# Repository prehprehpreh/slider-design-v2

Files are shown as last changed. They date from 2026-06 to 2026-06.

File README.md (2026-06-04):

# Slider Design V2

Camera slider project with 3D printed parts, Arduino control, and Windows controller.

## Project Structure

- `3d_models/` - STL files for 3D printed slider components
- `firmware/` - Arduino sketch files for slider control
- `controller/` - Windows desktop controller application

## Components

### 3D Models
- `2040_slider_carriage_bottomV1.stl`
- `2040_slider_carriage_topV1.stl`
- `CameraUplateV1.stl`
- `Carriage_Base_V1.stl`
- `PanAxisCarriageV1.stl`

### Firmware
- Arduino Network Slider PTZ control
- CHATGPT Arduino Mega Code with NRF24

### Controller
- Windows Controller Python application

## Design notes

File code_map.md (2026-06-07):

# PTZ Slider — Code Map & System Analysis

> Generated after full analysis of the active Arduino Mega firmware and Python Windows controller.

---

## 1. System Architecture

```
PC Controller (Python/Kivy + Xbox gamepad)
    │ UDP send → Mega :44158
    │ UDP recv ← Mega :44159
    │ JSON persistence (~\Documents\Controller2\motor_params.json)
    ▼
Arduino Mega 2560
    ├── WIZ5100 Ethernet Shield
    ├── 128x64 I2C OLED (SSD1306 @ 0x3C)
    └── 4x stepper drivers (AccelStepper + MultiStepper)

Planned:
Arduino Nano + NRF24L01+PA+LNA ←→ Mega (needs NRF24 input path)
```

---

## 2. Hardware Pinout (Mega)

| Motor | Role | Step | Dir | MS1 | MS2 | TMC EN |
|---|---|---|-----|-----|-----|---|
| 1 | **Slide** | 3 | 2 | 10 | 11 | — |
| 2 | **Pan** | 31 | 30 | 32 | 33 | — |
| 3 | **Tilt** | 45 | 44 | 40 | 41 | — |
| 4 | **Zoom** | 48 | 49 | 37 | 35 | 50 |

- All MS pins set `HIGH` in `setup()` (likely 1/16 microstep).
- **Bug:** `ms1Pin2` is never set `HIGH` in `setup()`; line 81 writes `ms2Pin2` twice.

---

## 3. Input → Motor Mapping

| Source | Python Var | Arduino Var | Motor | Role |
|---|---|---|---|---|
| Left Stick X | `x_axis_left` | `x_axis_value_left` | Stepper1 | Slide |
| Left Stick Y | `y_axis_left` | — | — | **Unused** |
| Right Stick X | `x_axis_right` | `x_axis_value_right` | Stepper2 | Pan |
| Right Stick Y | `y_axis_right` | `y_axis_value` | Stepper3 | Tilt |
| Left Trigger | `trigger_left_mapped` | `trigger_left` | Stepper4 | Zoom (+) |
| Right Trigger | `trigger_right_mapped` | `trigger_right` | Stepper4 | Zoom (-) |

- Triggers are combined in Arduino: `target = (trigger_right + trigger_left) * 100`.
- Right trigger is stored negative in Python (`-(event.state / 255.0)`).

---

## 4. UDP Protocol

### PC → Mega (Commands)

| Command | Payload | Handler | Notes |
|---|---|---|---|
| `SET_JOYSTICK` | `xL,xR,yR,tL,tR` (5 floats) | `handleUDPRequests()` | Real-time analog control |
| `SEND_CURRENT_POS` | — | `sendCurrentMotorPositions()` | Triggers reply with positions |
| `SAVE_POS` | — | `saveMotorPositions()` | **Dead code** — no Python caller |
| `RECALL_POS` | — | `recallMotorPositions()` | **Dead code** — no Python caller |
| `SAVE_A` | — | `savePresetA()` | Save current pos to Preset A |
| `SAVE_B` | — | `savePresetB()` | Save current pos to Preset B |
| `RECALL_A` | — | `recallPresetA()` | Blocking syncMove to Preset A |
| `RECALL_B` | — | `recallPresetB()` | Blocking syncMove to Preset B |
| `UPDATE_LOOP` | `true` or `false` | Sets `loopPresets` | Enables/disables loop flag on Mega |
| `INCREASE_SPEED` | — | `msSpeed += 200` | Bumps slide max speed |
| `DECREASE_SPEED` | — | `msSpeed -= 200` | Drops slide max speed |

### Mega → PC (Replies)

| Message | Triggered By | Python Handler |
|---|---|---|
| `CURRENT_POS:m1,m2,m3,m4` | `SEND_CURRENT_POS` | `update_motor_positions()` |
| `PRESET_POS_A:m1,m2,m3,m4,PRESET_POS_B:m1,m2,m3,m4` | `SAVE_A` or `SAVE_B` | `update_preset_positions()` |
| `MSSPEED:val` | Speed change / `SET_MSSPEED` | Updates label + saves JSON |
| `PRESET_A_DONE` | End of `recallPresetA()` | If `loop_state`, sends `RECALL_B` |
| `PRESET_B_DONE` | End of `recallPresetB()` | If `loop_state`, sends `RECALL_A` |

### Setup Handshake (Mega Boot)

1. Mega waits for **any** UDP packet to learn controller IP/port.
2. Mega sends `GET_CURRENT_POS`.
3. Python loads `motor_params.json` and replies with:
   - `SET_POS m1,m2,m3,m4`
   - `SET_PRESET_A m1,m2,m3,m4`
   - `SET_PRESET_B m1,m2,m3,m4`
   - `SET_MSSPEED val`
4. Mega sets stepper current positions from saved values.
5. OLED shows `Data Loaded` or `Data Failed`.

---

## 5. Mega Firmware — Key Behaviors

### Main Loop (`loop()`)

```cpp
loop() {
    handleUDPRequests();          // Parse UDP, may BLOCK during preset recall
    if (5ms elapsed) {
        controlStepperMotors();  // Calculate target speeds, apply accel curves
    }
    stepper1.runSpeed();          // Execute steps
    stepper2.runSpeed();
    stepper3.runSpeed();
    stepper4.runSpeed();
}
```

### Motor Control (`controlStepperMotors()`)

- **Slide (Stepper1):** Custom asymmetric acceleration.
  - If speeding up: `current += min(10, diff * 0.002 + 0.02)`
  - If slowing down: `current -= min(10, -diff * 0.002 + 0.02)`
- **Pan (Stepper2), Tilt (Stepper3), Zoom (Stepper4):** Simple linear ramping.
  - `accel = 0.6` (pan/tilt), `0.75` (zoom)
  - `decel = 0.6` (pan/tilt), `0.75` (zoom)
- **Deadzone:** 10 (after scaling joystick *100), so ~10% deadzone.
- `max_speed_left` (slide) is dynamic, default 2000.
- Pan/tilt/zoom max speeds are hardcoded `const`: 100, 100, 75.

### syncMove (Blocking Preset Recall)

- Called by `recallPresetA()` and `recallPresetB()`.
- If already within `tolerance` (1000 steps) on **all 4 axes**, immediately sends `PRESET_X_DONE`.
- Otherwise:
  - Sets individual `moveTo()` targets.
  - Computes proportional max speed per motor: `speed = maxSpeed * (motorDistance / longestDistance)`.
  - **Blocking while-loop** calls `stepper.run()` until all motors arrive.
  - After arrival, resets all max speeds to `max_speed_left` and accel to 400.
  - Sends `PRESET_X_DONE`.
- **Critical:** During `syncMove`, `handleUDPRequests()` is NOT called. The Mega is unresponsive to new UDP packets and joystick updates.

### MultiStepper

- Added to all 4 steppers but only used by `recallMotorPositions()` (`SAVE_POS`/`RECALL_POS`).
- These commands have no callers in the Python app, so `MultiStepper` is effectively **unused**.

---

## 6. Python Controller — Key Behaviors

### Threads

| Thread | Purpose |
|---|---|
| Main | Kivy UI event loop |
| `joystick_input_thread` | Blocks on `inputs.get_gamepad()`, parses ABS/Key events, updates globals |
| `udp_receive_thread` | Blocks on `sock.recvfrom()`, parses Mega replies, orchestrates preset loop |

### Kivy Clock Intervals

| Function | Interval | Purpose |
|---|---|---|
| `send_joystick_data()` | 0.1s | Sends `SET_JOYSTICK` + `SEND_CURRENT_POS` |
| `virtualloop()` | 0.1s | If enabled, computes slider direction and sends `SET_JOYSTICK` |
| `save_params_periodically()` | 1.0s | Saves JSON if 5s elapsed since last save |

### Gamepad Mapping

| Input | Event Code | Action |
|---|---|---|
| Left Stick X | `ABS_X` | `x_axis_left` |
| Left Stick Y | `ABS_Y` | `y_axis_left` (**unused**) |
| Right Stick X | `ABS_RX` | `x_axis_right` |
| Right Stick Y | `ABS_RY` | `y_axis_right` |
| Left Trigger | `ABS_Z` | `trigger_left_mapped` |
| Right Trigger | `ABS_RZ` | `trigger_right_mapped` (negative) |
| D-Pad Left | `ABS_HAT0X = -1` | `RECALL_A` |
| D-Pad Right | `ABS_HAT0X = +1` | `RECALL_B` |
| D-Pad Up | `ABS_HAT0Y = -1` | Enable `virtualloop` |
| D-Pad Down | `ABS_HAT0Y = +1` | Disable `virtualloop` |
| A (South) | `BTN_SOUTH` | `UPDATE_LOOP false` + disable `loop_state` |
| Y (North) | `BTN_NORTH` | `UPDATE_LOOP true` + enable `loop_state` |
| X (West) | `BTN_WEST` | `SAVE_A` |
| B (East) | `BTN_EAST` | `SAVE_B` |
| RB | `BTN_TR` | `INCREASE_SPEED` |
| LB | `BTN_TL` | `DECREASE_SPEED` |

### Two Different Loop Modes

1. **`loop_state` (Preset Sync Loop):**
   - Enabled by `UPDATE_LOOP true` / disabled by `UPDATE_LOOP false`.
   - Python orchestrates A↔B by listening for `PRESET_A_DONE` / `PRESET_B_DONE` from Mega.
   - When `PRESET_A_DONE` arrives, Python waits 0.5s then sends `RECALL_B`.
   - When `PRESET_B_DONE` arrives, Python waits 0.5s then sends `RECALL_A`.
   - Mega handles the actual synchronized motion via `syncMove`.
   - **Result:** All 4 motors move proportionally between full preset positions.

2. **`virtualloop_enabled` (Software Position Loop):**
   - Python reads `current_pos1_label.text` to know slider position.
   - Computes `direction = +1` or `-1` to reach next target (`preset_a_slide` or `preset_b_slide`).
   - Sends `SET_JOYSTICK direction,xR,yR,tL,tR` every 0.1s.
   - Only drives Stepper1 (slide). Pan/tilt/zoom remain manually controlled.
   - Toggles target when within `tolerance` (600 steps).
   - **Result:** Slider ping-pongs between A and B using the normal joystick control path.

### JSON Persistence

**File:** `~/Documents/Controller2/motor_params.json`

```json
{
    "current_positions": { "motor1": 0, "motor2": 0, "motor3": 0, "motor4": 0 },
    "preset_a": { "motor1": 0, "motor2": 0, "motor3": 0, "motor4": 0 },
    "preset_b": { "motor1": 0, "motor2": 0, "motor3": 0, "motor4": 0 },
    "ms_speed": 800,
    "udp_ip": "192.168.5.60",
    "invert_left": false,
    "invert_right": false,
    "invert_ry": false,
    "sensitivity_right": 1.0
}
```

- Loaded at app startup; defaults used if missing.
- `current_positions` and presets updated from Mega replies.
- `sensitivity_right` scales `x_axis_right` and `y_axis_right` in Python.
- Saved automatically every 5 seconds.

---

## 7. Known Issues / Observations

- **`ms1Pin2` never set HIGH** in `setup()` (typo on line 81).
- **`findBiggestNumFloatArray`** takes unused `String option` parameter.
- **`y_axis_left` parsed but never sent** to Arduino (left stick Y is dead).
- **`SAVE_POS` / `RECALL_POS`** have Arduino handlers but no Python callers.
- **`multiStepper`** configured but unused for preset recalls.
- **Mega cannot distinguish multiple UDP clients.** `sendUDPMessage()` replies to `Udp.remoteIP()` / `Udp.remotePort()`. If PC and Nano both send, replies may go to the wrong device.
- **`virtualloop`** parses label text to get position rather than using a dedicated state variable.
- **Pan/tilt/zoom max speeds are hardcoded** `const` on Mega. Changing them requires firmware modification.

---

## 8. Implications for Nano+NRF24 Controller

To add the Nano remote, the Mega firmware will likely need the following changes:

### Dual-Path Input
The Mega must accept commands from both Ethernet (PC) and NRF24 (Nano). The archived code in `ORIGINAL FILES DO NOT EDIT/` had a dual-path structure that can be used as reference.

### Reply Routing
`sendUDPMessage()` currently replies to the last UDP sender. With two controllers, the Mega needs to either:
- Broadcast state updates to both paths, or
- Track which controller sent the request and reply accordingly, or
- Make the Nano a "fire-and-forget" sender that does not wait for replies.

### NRF24 Payload Limit (32 bytes)
The current ASCII protocol (`SET_JOYSTICK 0.123,0.456, ...`) exceeds 32 bytes easily. A **compact binary protocol** is strongly recommended for the Nano↔Mega radio link.

### Persistence Without PC
If the PC is offline, the Nano must provide initial positions/presets on Mega boot, or the Mega must store them internally (EEPROM / SD card).

### Nano Menu System
The Nano OLED will display:
- Slider speed (`msSpeed`)
- Joystick sensitivity
- Invert controls toggles
- A **Start button** to exit the menu and save changes.

These settings must either be applied on the Nano before transmission or communicated to the Mega.

### syncMove Blocking
During preset recall, the Mega is unresponsive for the duration of the move. The Nano should expect this, or the firmware should be refactored to make `syncMove` non-blocking (state-machine driven in `loop()`).

### Loop Orchestration
Currently `loop_state` (A↔B preset sync loop) is managed entirely by Python. If the Nano replaces the PC, it must either:
- Replicate the Python loop logic on the Nano, or
- Teach the Mega to loop autonomously (store a `loopActive` flag and self-trigger recalls).

### State Conflicts
If both PC and Nano are online simultaneously, they may send conflicting `SET_JOYSTICK` values or commands. The firmware currently processes every packet in arrival order with no priority or arbitration.

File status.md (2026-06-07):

# PTZ Slider Project Status

## Hardware

### Slider (On-Device) — Arduino Mega
- 4x stepper motors (Slide, Pan, Tilt, Zoom) via `AccelStepper` + `MultiStepper`
- WIZ5100 Ethernet shield for network control
- 128x64 OLED status display (SSD1306, I2C @ 0x3C)

### Network Controller — Windows PC
- Python/Kivy app with Xbox gamepad via `inputs` library
- UDP communication to/from Mega on ports 44158/44159
- JSON persistence at `~/Documents/Controller2/motor_params.json`

### Physical Wireless Controller — In Progress
- **Prototype board:** Arduino Uno (same pinout as final Nano, easier breadboarding)
- **Final board:** Arduino Nano (ATmega328P)
- **Radio:** NRF24L01+PA+LNA with breakout adapter (3.3V regulator on-board)
- **Display:** 0.96" SSD1306 OLED 128x64 I2C
- **Inputs:** 2x HW-504 analog joysticks, 7x tactile buttons, 1x mini SPDT toggle (power)
- **Button layout:** D-pad Left/Right (left side), A/B/X/Y (right side), Start (center)
- **Archived NRF24 Mega code:** `ORIGINAL FILES DO NOT EDIT/` — prior dual UDP+NRF24 firmware, kept as reference

---

## Current State

### Completed
- Network-based control system fully functional (Mega + Python/Kivy + Xbox gamepad)
- Real-time stepper control with acceleration curves and deadzone remapping
- Preset system: Save/Recall A and B positions across all 4 motors
- Preset looping (A ↔ B) orchestrated by Python controller via `PRESET_A/B_DONE` messages
- Virtual loop mode (software position tracking) in Python controller
- JSON persistence on PC for positions, presets, speed, inversion, sensitivity
- Initial setup handshake: Mega requests saved state from PC on boot
- Full code analysis documented in `code_map.md`
- Wiring diagram for Uno/Nano prototype documented in `wiring_diagram_uno_nano.md`

### Completed — NRF24 Physical Controller
- Dual-mode Mega firmware receives UDP or NRF24 (auto-switches based on Ethernet link)
- Compact binary packet protocol: 8-byte `ControllerPacket` with XOR checksum
- All 4 joystick axes, 6 buttons, OLED popup messages on actions
- **Loop control:** Nano broadcasts `loopEnabled` in bit 7 of every packet; Mega drains radio FIFO between `syncMove()` calls to get latest state
- **Dead battery handling:** If no packet for 5s, Mega defaults to continuing the loop
- Freeze bug fixed: `syncMove()` early-returns when already at target position

### Decided — Nano Controller Design
- **No virtual loop on Nano** — too complex, not needed on the physical remote
- **Nano sends:** joystick values + button states in compact binary every 50ms
- **NRF24 protocol:** 8-byte binary `ControllerPacket`, magic byte `0xAB`, bit 7 of `buttons` = loop state
- **Menu mode:** Start button toggles between normal control and OLED settings menu
  - In menu mode, no signals sent to Mega
  - Menu controls: speed, joystick sensitivity, invert axes
  - Settings saved to Nano EEPROM on Start press (exit)
  - Skeleton menu system to be built from the start, populated later
- **Prototyping on Uno** before finalizing on Nano — identical pinout

### Nano Pin Assignments (Uno + Nano)
| Function | Pin |
|---|-----|
| NRF24 CE | D8 |
| NRF24 CSN | D9 |
| NRF24 MOSI | D11 |
| NRF24 MISO | D12 |
| NRF24 SCK | D13 |
| OLED SDA | A4 |
| OLED SCL | A5 |
| Left Joystick X | A0 |
| Left Joystick Y | A1 |
| Right Joystick X | A2 |
| Right Joystick Y | A3 |
| Start Button | D2 |
| Button X (Save A) | D3 |
| Button Y (Loop ON) | D4 |
| D-pad Left (Recall A) | D5 |
| D-pad Right (Recall B) | D6 |
| Button A (Loop OFF) | D7 |
| Button B (Save B) | D10 |

---

## Open Decisions
1. **Where do presets live when PC is offline?**
   - Mega EEPROM? Nano EEPROM? Volatile only?
2. **Position feedback to Nano OLED?**
   - Requires Mega to broadcast `CURRENT_POS` back over NRF24

---

## Next Steps
1. Test loop stop/start repeatedly in a live run to confirm reliability
2. Add menu system to Nano (speed, sensitivity, invert axes) via Start button toggle
3. Save/load settings to Nano EEPROM
4. Update `README.md` to reflect current dual-mode firmware architecture
5. Consider Mega EEPROM persistence for presets when PC is offline

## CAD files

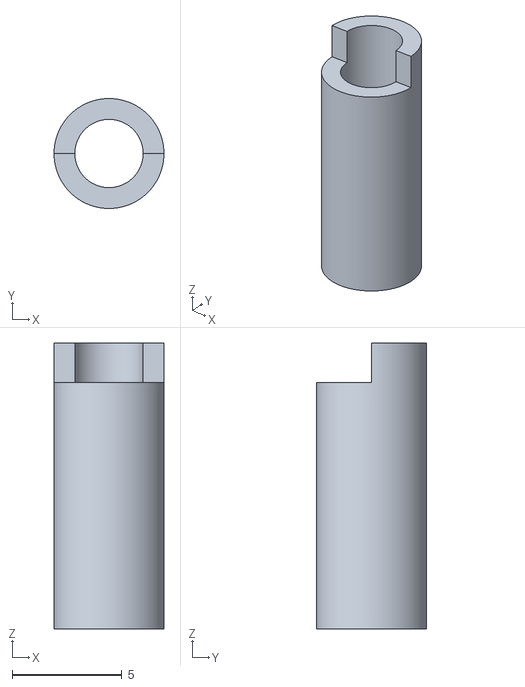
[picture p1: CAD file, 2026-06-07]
3d_models/3mm_to_5mm_wheel_bearing_spacer_centred.stl
5.00 x 5.00 x 13.0

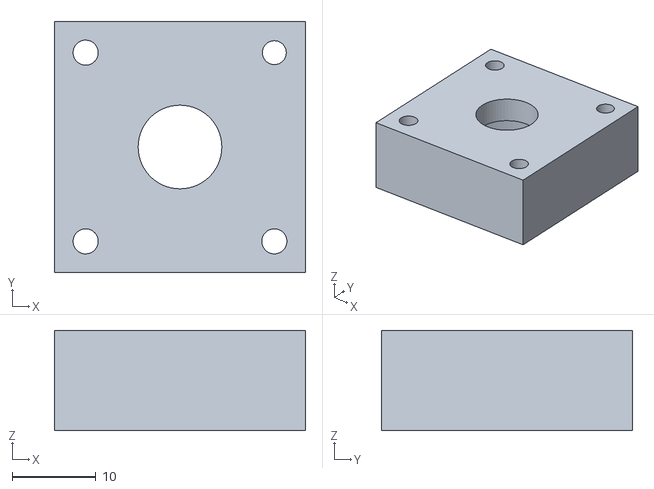
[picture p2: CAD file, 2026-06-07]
3d_models/PanBearingHolderV1.stl
30.0 x 30.0 x 12.0

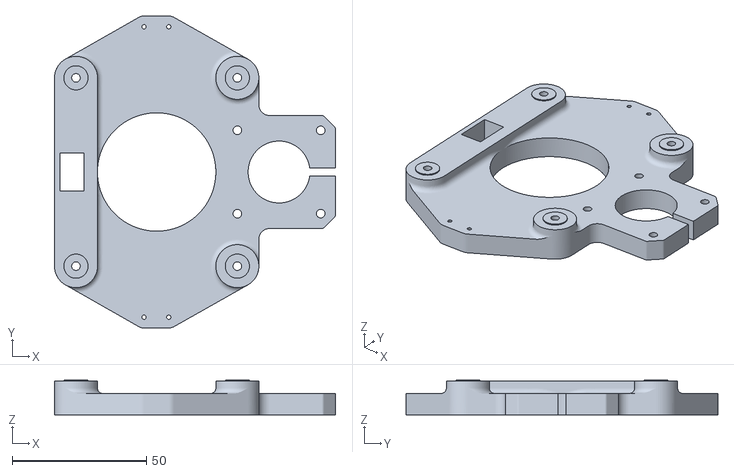
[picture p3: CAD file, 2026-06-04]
3d_models/2040_slider_carriage_bottomV1.stl
104.5 x 116.0 x 13.0

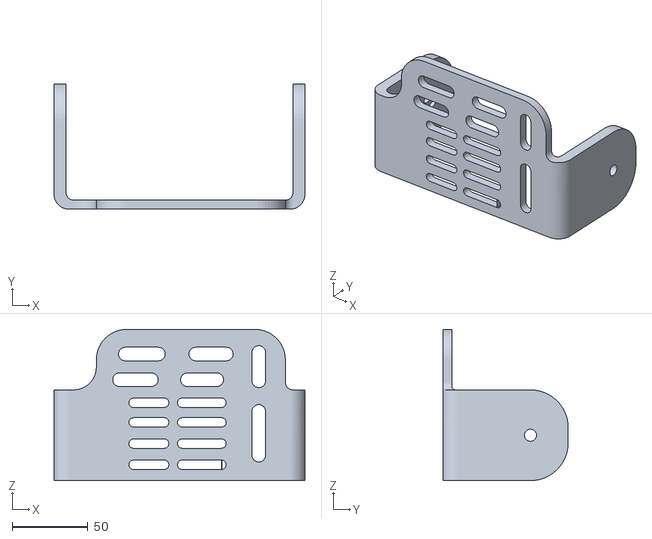
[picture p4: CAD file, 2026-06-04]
3d_models/CameraUplateV1.stl
166.0 x 83.0 x 100.0

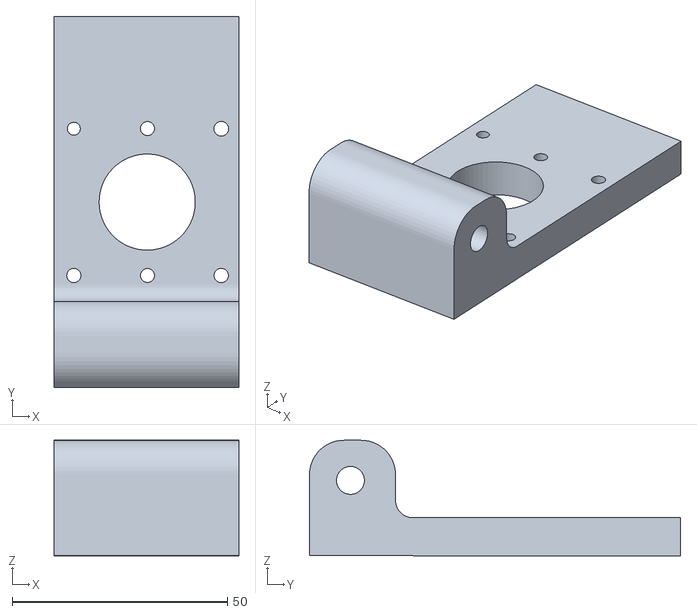
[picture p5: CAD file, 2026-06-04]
3d_models/Carriage_Base_V1.stl
43.0 x 86.2 x 26.8

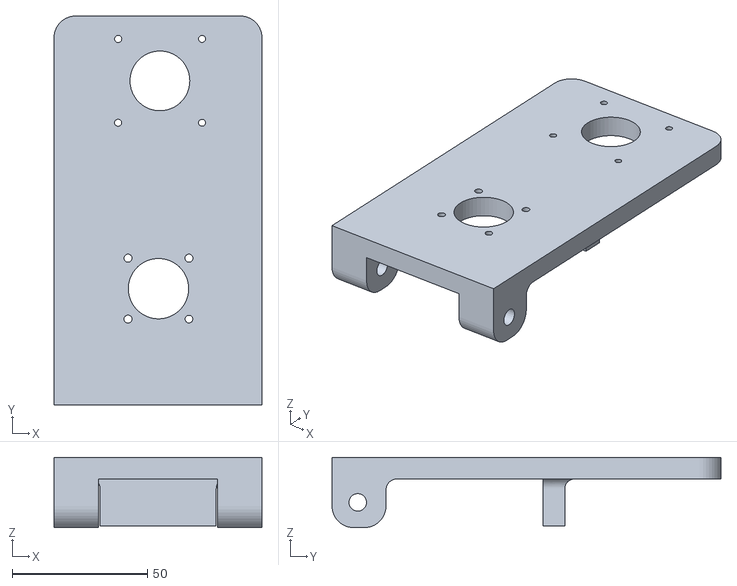
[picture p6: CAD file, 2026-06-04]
3d_models/PanAxisCarriageV1.stl
77.0 x 144.0 x 26.0

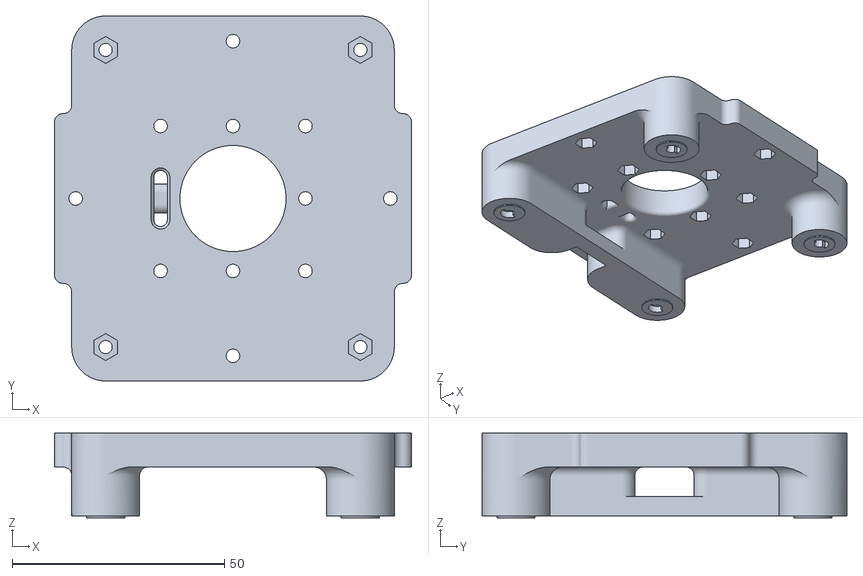
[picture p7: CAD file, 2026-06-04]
3d_models/2040_slider_carriage_topV1.stl
84.1 x 86.0 x 20.0

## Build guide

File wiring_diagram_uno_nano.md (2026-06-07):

# Uno/Nano Controller - Wiring Diagram

## Pin Reference

```
                    ┌─────────────────────────────────────────┐
                    │           ARDUINO UNO/NANO              │
                    │                                         │
    NRF24 CE ───────┤ D8                                      │
    NRF24 CSN ──────┤ D9                                      │
    Button B ───────┤ D10                                     │
                    │                                         │
    NRF24 MOSI ─────┤ D11 (ICSP)                              │
    NRF24 MISO ─────┤ D12 (ICSP)                              │
    NRF24 SCK ──────┤ D13 (ICSP)                              │
                    │                                         │
    OLED SDA ───────┤ A4 (I2C)                                │
    OLED SCL ───────┤ A5 (I2C)                                │
                    │                                         │
    L-Joystick Y ───┤ A1                                      │
    L-Joystick X ───┤ A0                                      │
    R-Joystick Y ───┤ A3                                      │
    R-Joystick X ───┤ A2                                      │
                    │                                         │
    Start Btn ──────┤ D2                                      │
    Button X ───────┤ D3                                      │
    Button Y ───────┤ D4                                      │
    D-pad Left ─────┤ D5                                      │
    D-pad Right ────┤ D6                                      │
    Button A ───────┤ D7                                      │
                    │                                         │
                    │   VIN ────┐                             │
                    │   GND ────┼──┐                          │
                    │   5V ─────┼──┼──┐                       │
                    │   3.3V ───┤  │  │                       │
                    └───────────┼──┼──┼───────────────────────┘
                                │  │  │
                                │  │  │
            ┌───────────────────┘  │  └───────────────┐
            │                      │                  │
            ▼                      ▼                  ▼
     ┌────────────┐        ┌────────────┐    ┌────────────┐
     │ TOGGLE     │        │  GND BUS   │    │  5V BUS    │
     │ SWITCH     │        │            │    │            │
     │ (Battery+) │        │ •────────  │    │ •────────  │
     └────────────┘        └────────────┘    └────────────┘
```

---

## Component Wiring Details

### 1. NRF24L01+ Breakout Adapter (Top-Left Area)

```
         ┌────────────────────────────────┐
         │   NRF24L01+ PA+LNA Breakout    │
         │                                │
         │  ┌──────────────────────────┐  │
         │  │  IRQ  │ CE │ CSN │ MOSI │  │
         │  │   NC  │ D8 │ D9  │  D11 │  │
         │  ├──────────────────────────┤  │
         │  │ MISO  │ SCK│ GND │  VCC │  │
         │  │  D12  │ D13│ GND │  5V  │  │
         │  └──────────────────────────┘  │
         │         8-Pin Header           │
         └────────────────────────────────┘
```

**Connections:**
- VCC → 5V (breakout has 3.3V regulator)
- GND → GND
- MOSI → D11
- MISO → D12  
- SCK → D13
- CE → D8
- CSN → D9
- IRQ → Not connected

---

### 2. OLED SSD1306 128x64 I2C (Top Area)

```
        ┌─────────────────────┐
        │    OLED DISPLAY   │
        │   ┌───────────┐   │
        │   │           │   │
        │   │  128x64   │   │
        │   │   I2C     │   │
        │   │           │   │
        │   └───────────┘   │
        │                   │
        │  VCC GND SCL SDA  │
        │   │   │   │   │   │
        └───┼───┼───┼───┼───┘
            │   │   │   │
            5V  GND A5  A4
```

**Connections:**
- VCC → 5V
- GND → GND
- SCL → A5
- SDA → A4

---

### 3. Left Joystick - HW-504 (Slide Control)

```
           ┌───────────────────┐
           │   HW-504 Module   │
           │                   │
           │        ↑          │
           │     Y-axis        │
           │    (unused)       │
           │        ↓          │
           │                   │
           │ ←  X-axis  →      │
           │   (Slide L/R)     │
           │                   │
           │  ┌─────────────┐  │
           │  │   Push-btn  │  │
           │  │   (unused)  │  │
           │  └─────────────┘  │
           └───────────────────┘
           
           Pinout (from left to right):
           ┌───┬───┬───┬───┬───┐
           │GND│+5V│VRX│VRY│ SW│
           └───┴───┴───┴───┴───┘
            │   │   │   │   │
            │   │   │   │   └── NC (or D2 for joystick button)
            │   │   │   └────── A1 (Y-axis, currently unused)
            │   │   └────────── A0 (X-axis, Slide control)
            │   └────────────── 5V
            └────────────────── GND
```

---

### 4. Right Joystick - HW-504 (Pan/Tilt Control)

```
           ┌───────────────────┐
           │   HW-504 Module   │
           │                   │
           │        ↑          │
           │    Y-axis         │
           │   (Tilt U/D)      │
           │        ↓          │
           │                   │
           │ ←  X-axis  →      │
           │  (Pan L/R)        │
           │                   │
           │  ┌─────────────┐  │
           │  │   Push-btn  │  │
           │  │   (unused)  │  │
           │  └─────────────┘  │
           └───────────────────┘
           
           Pinout:
           ┌───┬───┬───┬───┬───┐
           │GND│+5V│VRX│VRY│ SW│
           └───┴───┴───┴───┴───┘
            │   │   │   │   │
            │   │   │   │   └── NC (or D10 for joystick button)
            │   │   │   └────── A3 (Y-axis, Tilt)
            │   │   └────────── A2 (X-axis, Pan)
            │   └────────────── 5V
            └────────────────── GND
```

---

### 5. Button Layout - Controller Face

```
         ╔═══════════════════════════════════════╗
         ║                                       ║
         ║           ┌─────────┐      OLED       ║
         ║           │ START   │    ┌─────┐      ║
         ║           │   D2    │    │     │      ║
         ║           └─────────┘    │ SSD │      ║
         ║                          │1306 │      ║
         ║   ┌─────┐                │12864│      ║
         ║   │  ←  │                └─────┘      ║
         ║   │ D5  │                           ║
         ║   ├─────┤                             ║
         ║   │  →  │                             ║
         ║   │ D6  │                             ║
         ║   └─────┘                             ║
         ║                                       ║
         ║   D-PAD (Left)        BUTTONS (Right) ║
         ║   (2-way)                               ║
         ║                              ┌───┐    ║
         ║                         ┌────┤ Y │    ║
         ║                         │ D4 └───┘    ║
         ║                    ┌────┴────┐        ║
         ║                   ┌┤   X     ├┐       ║
         ║                   ├┤  D3     ├┤       ║
         ║                   └┤    ┌────┼┘       ║
         ║                    └───┬┘ B  │        ║
         ║                        │ D10 │        ║
         ║                   ┌────┴────┘        ║
         ║                   │    A             ║
         ║                   │   D7             ║
         ║                   └────────          ║
         ║                                       ║
         ╚═══════════════════════════════════════╝
```

**Button Wiring (ALL buttons):**
- One side of button → Arduino Pin
- Other side of button → GND
- Code uses `INPUT_PULLUP`, so LOW = pressed

**Button Functions in Normal Mode:**
- **D-pad Left (D5):** Recall Preset A
- **D-pad Right (D6):** Recall Preset B
- **A (D7):** Save Preset A
- **B (D10):** Save Preset B
- **X (D3):** Loop ON
- **Y (D4):** Loop OFF
- **Start (D2):** Enter/Exit Menu

---

### 6. Power Switch

```
    Battery (+) ──┬──► (Toggle Switch Center Pin)
                  │
                  │   ┌───────────────┐
                  └──►│  Toggle Switch │
                      │   (SPDT)       │
                      │   ┌──┬──┬──┐   │
                      └───┤NC│ C │NO├───┘
                          └──┴──┴──┘
                               │
                               ▼
                         To Arduino
                            VIN
                               
    Battery (-) ─────────► To Arduino
                              GND
```

**Simple Inline Wiring:**
- Cut positive battery wire
- Connect one end to switch center pin
- Connect other end to one outer pin
- When switch is flipped that direction, circuit completes

---

## Breadboard Layout - Visual Guide

```
    ┌─────────────────────────────────────────────────────────────────────────┐
    │                          BREADBOARD TOP VIEW                            │
    │                                                                         │
    │  ┌─────────────────────────────────────────────────────────────────┐   │
    │  │                         POWER RAILS                              │   │
    │  │  ┌───────────────┐    ┌───────────────┐    ┌───────────────┐  │   │
    │  │  │ RED (5V)      │    │ BLU (3.3V)    │    │ BLK (GND)     │  │   │
    │  │  │ █████████████ │    │ (unused)      │    │ █████████████ │  │   │
    │  │  └───────────────┘    └───────────────┘    └───────────────┘  │   │
    │  └─────────────────────────────────────────────────────────────────┘   │
    │                                                                         │
    │  ┌─────────────────────────────────────────────────────────────────┐   │
    │  │  AREA 1: NRF24 (Top Left)                                        │   │
    │  │                                                                  │   │
    │  │        ┌────────────────────────┐                               │   │
    │  │        │   NRF24 Breakout       │                               │   │
    │  │        │                        │                               │   │
    │  │        │  VCC ─────► RED rail  │                               │   │
    │  │        │  GND ─────► BLK rail   │                               │   │
    │  │        │  D11 ─────► Blue wire  │                               │   │
    │  │        │  D12 ─────► Yel wire   │                               │   │
    │  │        │  D13 ─────► Wht wire   │                               │   │
    │  │        │  D8  ─────► Org wire   │                               │   │
    │  │        │  D9  ─────► Ppl wire   │                               │   │
    │  │        └────────────────────────┘                               │   │
    │  └─────────────────────────────────────────────────────────────────┘   │
    │                                                                         │
    │  ┌─────────────────────────────────────────────────────────────────┐   │
    │  │  AREA 2: OLED (Top Center)                                       │   │
    │  │                                                                  │   │
    │  │        ┌────────────────────────┐                               │   │
    │  │        │    OLED 128x64       │                               │   │
    │  │        │                      │                               │   │
    │  │        │  VCC ─────► RED rail │                               │   │
    │  │        │  GND ─────► BLK rail  │                               │   │
    │  │        │  SCL ─────► A5        │                               │   │
    │  │        │  SDA ─────► A4        │                               │   │
    │  │        └────────────────────────┘                               │   │
    │  └─────────────────────────────────────────────────────────────────┘   │
    │                                                                         │
    │  ┌─────────────────────────────────────────────────────────────────┐   │
    │  │  AREA 3: JOYSTICKS (Middle)                                      │   │
    │  │                                                                  │   │
    │  │   Left Joystick              Right Joystick                     │   │
    │  │   ┌────────────┐             ┌────────────┐                   │   │
    │  │   │   ──────   │             │   ──────   │                   │   │
    │  │   │  │    │   │             │  │    │   │                   │   │
    │  │   │   ──────   │             │   ──────   │                   │   │
    │  │   └────────────┘             └────────────┘                   │   │
    │  │      │  │  │  │                │  │  │  │                     │   │
    │  │      │  │  │  │                │  │  │  │                     │   │
    │  │     GND 5V A0 A1              GND 5V A2 A3                    │   │
    │  │      │  │  │  │                │  │  │  │                     │   │
    │  │      │  │  │  │                │  │  │  │                     │   │
    │  │      └──┴──┴──┘                └──┴──┴──┘                     │   │
    │  │         │                        │                            │   │
    │  │         └───────► Both share RED and BLK rails                │   │
    │  └─────────────────────────────────────────────────────────────────┘   │
    │                                                                         │
    │  ┌─────────────────────────────────────────────────────────────────┐   │
    │  │  AREA 4: BUTTONS (Bottom) - Left Side = D-Pad (2-way)           │   │
    │  │                                                                  │   │
    │  │                                                                  │   │
    │  │           ┌───┐    ┌───┐                                         │   │
    │  │           │ ← │    │ → │                                         │   │
    │  │       D5  └───┘    └───┘  D6                                   │   │
    │  │      (Recall A)   (Recall B)                                     │   │
    │  │                                                                  │   │
    │  │  Center: ┌─────────┐  (Start/Menu)                             │   │
    │  │          │   ●     │  D2                                        │   │
    │  │          └─────────┘                                             │   │
    │  │                                                                  │   │
    │  │  Right Side: ┌───┐ ┌───┐                                       │   │
    │  │              │ Y │ │ X │  D4, D3                               │   │
    │  │              └───┘ └───┘                                       │   │
    │  │              ┌───┐ ┌───┐                                       │   │
    │  │              │ B │ │ A │  D10, D7                              │   │
    │  │              └───┘ └───┘                                       │   │
    │  │                                                                  │   │
    │  │  ALL buttons: One pin to Arduino, other pin to GND             │   │
    │  └─────────────────────────────────────────────────────────────────┘   │
    │                                                                         │
    │  ┌─────────────────────────────────────────────────────────────────┐   │
    │  │  AREA 5: ARDUINO (Right Edge)                                    │   │
    │  │                                                                  │   │
    │  │   ┌──────────────────────────────────────┐                      │   │
    │  │   │          ARDUINO UNO/NANO            │                      │   │
    │  │   │                                      │                      │   │
    │  │   │  D0  D1  D2  D3  D4  D5  D6  D7  D8  │                      │   │
    │  │   │  NC  NC  ○   ○   ○   ○   ○   ○   ○   │  ○ = used            │   │
    │  │   │                                      │                      │   │
    │  │   │  D9  D10 D11 D12 D13 GND AREF SDA  │                      │   │
    │  │   │  ○   ○   ○   ○   ○   BLK NC  A4    │                      │   │
    │  │   │                                      │                      │   │
    │  │   │  SCL ─► A5                           │                      │   │
    │  │   │  ICSP header (for NRF24 SPI)          │                      │   │
    │  │   │                                      │                      │   │
    │  │   │  PWR: VIN GND 5V  3.3V              │                      │   │
    │  │   │       │   │   │   NC                │                      │   │
    │  │   │       │   │   │                     │                      │   │
    │  │   │       └───┴───┘                     │                      │   │
    │  │   │           │                        │                      │   │
    │  │   │           └──► To Power Switch     │                      │   │
    │  │   └──────────────────────────────────────┘                      │   │
    │  └─────────────────────────────────────────────────────────────────┘   │
    │                                                                         │
    └─────────────────────────────────────────────────────────────────────────┘
```

---

## Wire Color Code Suggestion

| Color | Use | Examples |
|---|-----|---|
| **Red** | 5V Power | VCC, +5V pins |
| **Black** | Ground | GND pins |
| **White** | Analog signals | Joystick X/Y |
| **Blue** | Digital/SPI | D11, D12, D13 |
| **Green** | Control signals | CE, CSN, Buttons |
| **Yellow** | I2C | SDA, SCL |
| **Orange** | Special functions | D8, D9 |
| **Purple** | Unused/Extra | — |

---

## Quick Reference - All Connections

| Component | Pin/Function | Arduino Pin | Notes |
|---|---|---|---|
| **NRF24** | VCC | 5V | Has regulator |
| | GND | GND | |
| | CE | D8 | |
| | CSN | D9 | |
| | MOSI | D11 | SPI |
| | MISO | D12 | SPI |
| | SCK | D13 | SPI |
| **OLED** | VCC | 5V or 3.3V | Check module |
| | GND | GND | |
| | SCL | A5 | I2C |
| | SDA | A4 | I2C |
| **L-Joystick** | +5V | 5V | |
| | GND | GND | |
| | VRX (X) | A0 | Slide |
| | VRY (Y) | A1 | Unused currently |
| **R-Joystick** | +5V | 5V | |
| | GND | GND | |
| | VRX (X) | A2 | Pan |
| | VRY (Y) | A3 | Tilt |
| **Buttons** | All one side | Pins D2, D3, D4, D5, D6, D7, D10 | Pullup enabled |
| | All other side | GND | Common ground |
| **Power** | Switch → VIN | VIN | 7-12V input |
| | Battery - | GND | Common ground |

---

## Uno vs Nano Differences

| Feature | Uno | Nano |
|---|-----|---|
| **Button X (D3)** | ✅ Available | ✅ Available |
| **Button Y (D4)** | ✅ Available | ✅ Available |
| **Breadboard** | Headers pre-installed | Solder or use adapter |
| **USB** | Standard B | Mini-B or Micro |
| **Size** | Larger | Smaller |

All 7 buttons work identically on both Uno and Nano using digital pins D2-D7 and D10.

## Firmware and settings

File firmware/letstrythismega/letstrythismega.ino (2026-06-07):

#include <AccelStepper.h>
#include <Ethernet.h>
#include <EthernetUDP.h>
#include <MultiStepper.h>
#include <SPI.h>
#include <Wire.h>
#include <Adafruit_SSD1306.h>
#include <RF24.h>

// Ethernet settings
byte mac[] = { 0xA8, 0x61, 0x0A, 0xAE, 0x03, 0x30 };
unsigned int localPort = 44158;
const bool USE_STATIC_IP = true;
IPAddress staticIP(192, 168, 1, 177);
EthernetUDP Udp;
char packetBuffer[255];

// NRF24 settings
#define NRF_CE  8
#define NRF_CSN 9
RF24 radio(NRF_CE, NRF_CSN);
const byte rfAddress[6] = "00001";

// Compact binary packet (must match Nano)
struct __attribute__((packed)) ControllerPacket {
    uint8_t magic;
    int8_t  lx;
    int8_t  ly;
    int8_t  rx;
    int8_t  ry;
    uint8_t buttons;
    uint8_t checksum;
};
ControllerPacket rxPacket;

// Define OLED settings
#define SCREEN_WIDTH 128
#define SCREEN_HEIGHT 64
#define OLED_RESET -1
Adafruit_SSD1306 display(SCREEN_WIDTH, SCREEN_HEIGHT, &Wire, OLED_RESET);
bool oledOK = false;

// Stepper motor pins
const int stepPin1 = 3, dirPin1 = 2, ms1Pin1 = 10, ms2Pin1 = 11;
const int stepPin2 = 31, dirPin2 = 30, ms1Pin2 = 32, ms2Pin2 = 33;
const int stepPin3 = 45, dirPin3 = 44, ms1Pin3 = 40, ms2Pin3 = 41;
const int stepPin4 = 48, dirPin4 = 49, ms1Pin4 = 37, ms2Pin4 = 35, tmcEnPin4 = 50;

AccelStepper stepper1(AccelStepper::DRIVER, stepPin1, dirPin1);
AccelStepper stepper2(AccelStepper::DRIVER, stepPin2, dirPin2);
AccelStepper stepper3(AccelStepper::DRIVER, stepPin3, dirPin3);
AccelStepper stepper4(AccelStepper::DRIVER, stepPin4, dirPin4);
MultiStepper multiStepper;

// Joystick input variables (buffered)
float x_axis_value_left = 0.0, x_axis_value_right = 0.0, y_axis_value = 0.0, trigger_left = 0.0, trigger_right = 0.0;
float msSpeed = 2000, slideSpeed = 20;
long saved_position1 = 0, saved_position2 = 0, saved_position3 = 0, saved_position4 = 0;
bool loopPresets = false;
bool autoLoopRunning = false;
long presetAPositions[] = {0, 0, 0, 0}, presetBPositions[] = {0, 0, 0, 0};

// Motor control variables
int max_speed_left = msSpeed;
const int max_speed_right = 100;
const int max_speed_y = 100;
const int max_speed_zoom = 75;

const float acceleration_rate_left = 10;
const float deceleration_rate_left = 10;
const float acceleration_rate_right = 0.6;
const float deceleration_rate_right = 0.6;
const float acceleration_rate_y = 0.6;
const float deceleration_rate_y = 0.6;
const float acceleration_rate_zoom = 0.75;
const float deceleration_rate_zoom = 0.75;

const int deadzone = 10;

float current_speed_left = 0;
float current_speed_right = 0;
float current_speed_y = 0;
float current_speed_zoom = 0;

// Timeout for waiting for controller response (ms) for positions/presets
const unsigned long CONTROLLER_TIMEOUT = 15000;
const unsigned long updateInterval = 5;
unsigned long previousMillis = 0;
const unsigned long displayInterval = 200;
unsigned long previousDisplayMillis = 0;

// Setup state flags
bool setupComplete = false;
bool posReceived = false;
bool presetAReceived = false;
bool presetBReceived = false;
bool ethernetActive = false;
uint8_t lastRemoteButtonMask = 0;

void setup() {
    Serial.begin(115200);
    while (!Serial) { ; }
    Serial.println(F("=== Mega PTZ Slider Boot ==="));
    Serial.println(F("1. Pins init..."));

    // Initialize hardware pins
    pinMode(ms1Pin1, OUTPUT); pinMode(ms2Pin1, OUTPUT);
    pinMode(ms1Pin2, OUTPUT); pinMode(ms2Pin2, OUTPUT);
    pinMode(ms1Pin3, OUTPUT); pinMode(ms2Pin3, OUTPUT);
    pinMode(ms1Pin4, OUTPUT); pinMode(ms2Pin4, OUTPUT);
    pinMode(tmcEnPin4, OUTPUT);
    digitalWrite(ms1Pin1, HIGH); digitalWrite(ms2Pin1, HIGH);
    digitalWrite(ms2Pin2, HIGH); digitalWrite(ms2Pin2, HIGH);
    digitalWrite(ms1Pin3, HIGH); digitalWrite(ms2Pin3, HIGH);
    digitalWrite(ms1Pin4, HIGH); digitalWrite(ms2Pin4, HIGH);
    digitalWrite(tmcEnPin4, LOW);

    Serial.println(F("2. Steppers init..."));
    // Initialize stepper settings
    stepper1.setMaxSpeed(max_speed_left);
    stepper2.setMaxSpeed(max_speed_left);
    stepper3.setMaxSpeed(max_speed_left);
    stepper4.setMaxSpeed(max_speed_left);
    multiStepper.addStepper(stepper1);
    multiStepper.addStepper(stepper2);
    multiStepper.addStepper(stepper3);
    multiStepper.addStepper(stepper4);

    Serial.println(F("3. Ethernet begin..."));
    if (USE_STATIC_IP) {
        Ethernet.begin(mac, staticIP);
        Serial.print(F("Static IP: ")); Serial.println(Ethernet.localIP());
    } else {
        Ethernet.begin(mac);
    }
    Serial.println(F("4. UDP begin..."));
    Udp.begin(localPort);
    Serial.println(F("5. Waiting 1s for link..."));
    delay(1000);

    Serial.println(F("6. Checking link status..."));
    EthernetLinkStatus link = Ethernet.linkStatus();
    ethernetActive = (link == LinkON);
    Serial.print(F("Ethernet link status: "));
    if (link == LinkON) Serial.println(F("ON"));
    else if (link == LinkOFF) Serial.println(F("OFF"));
    else Serial.println(F("UNKNOWN"));
    Serial.print(F("ethernetActive = ")); Serial.println(ethernetActive ? F("true") : F("false"));

    Serial.println(F("7. OLED init..."));
    Wire.begin();
    delay(100);
    oledOK = display.begin(SSD1306_SWITCHCAPVCC, 0x3C);
    if (oledOK) {
        Serial.println(F("OLED: OK"));
        display.clearDisplay();
        display.setTextSize(1);
        display.setTextColor(SSD1306_WHITE);
    } else {
        Serial.println(F("OLED: NOT FOUND"));
    }

    Serial.println(F("8. Mode selection..."));
    if (ethernetActive) {
        Serial.println(F("Mode: ETH (UDP)"));
        if (oledOK) {
            display.setCursor(0, 0);
            display.println("ETH Mode");
            display.println(Ethernet.localIP());
            display.display();
        }

        bool controllerFound = false;
        unsigned long waitStart = millis();
        while (!controllerFound && (millis() - waitStart < 10000)) {
            int packetSize = Udp.parsePacket();
            if (packetSize) {
                int len = Udp.read(packetBuffer, 255);
                if (len > 0) packetBuffer[len] = 0;
                controllerFound = true;
            }
            delay(10);
        }

        if (controllerFound) {
            int retryCount = 0;
            const int maxRetries = 3;
            while (retryCount < maxRetries && (!posReceived || !presetAReceived || !presetBReceived)) {
                sendUDPMessage("GET_CURRENT_POS");
                if (oledOK) {
                    display.clearDisplay();
                    display.setCursor(0, 0);
                    display.println("Requesting Data...");
                    display.setCursor(0, 10);
                    display.println(Ethernet.localIP());
                    display.display();
                }

                posReceived = false;
                presetAReceived = false;
                presetBReceived = false;
                unsigned long startTime = millis();

                while (millis() - startTime < CONTROLLER_TIMEOUT) {
                    int packetSize = Udp.parsePacket();
                    if (packetSize) {
                        int len = Udp.read(packetBuffer, 255);
                        if (len > 0) packetBuffer[len] = 0;
                        String response = String(packetBuffer);
                        if (response.startsWith("SET_POS")) {
                            int comma1 = response.indexOf(',');
                            int comma2 = response.indexOf(',', comma1 + 1);
                            int comma3 = response.indexOf(',', comma2 + 1);
                            saved_position1 = atol(response.substring(7, comma1).c_str());
                            saved_position2 = atol(response.substring(comma1 + 1, comma2).c_str());
                            saved_position3 = atol(response.substring(comma2 + 1, comma3).c_str());
                            saved_position4 = atol(response.substring(comma3 + 1).c_str());
                            stepper1.setCurrentPosition(saved_position1);
                            stepper2.setCurrentPosition(saved_position2);
                            stepper3.setCurrentPosition(saved_position3);
                            stepper4.setCurrentPosition(saved_position4);
                            posReceived = true;
                        } else if (response.startsWith("SET_PRESET_A")) {
                            int comma1 = response.indexOf(',');
                            int comma2 = response.indexOf(',', comma1 + 1);
                            int comma3 = response.indexOf(',', comma2 + 1);
                            presetAPositions[0] = atol(response.substring(12, comma1).c_str());
                            presetAPositions[1] = atol(response.substring(comma1 + 1, comma2).c_str());
                            presetAPositions[2] = atol(response.substring(comma2 + 1, comma3).c_str());
                            presetAPositions[3] = atol(response.substring(comma3 + 1).c_str());
                            presetAReceived = true;
                        } else if (response.startsWith("SET_PRESET_B")) {
                            int comma1 = response.indexOf(',');
                            int comma2 = response.indexOf(',', comma1 + 1);
                            int comma3 = response.indexOf(',', comma2 + 1);
                            presetBPositions[0] = atol(response.substring(12, comma1).c_str());
                            presetBPositions[1] = atol(response.substring(comma1 + 1, comma2).c_str());
                            presetBPositions[2] = atol(response.substring(comma2 + 1, comma3).c_str());
                            presetBPositions[3] = atol(response.substring(comma3 + 1).c_str());
                            presetBReceived = true;
                        } else if (response.startsWith("SET_MSSPEED")) {
                            msSpeed = response.substring(11).toFloat();
                            max_speed_left = msSpeed;
                        }
                    }
                    delay(10);
                    if (posReceived && presetAReceived && presetBReceived) break;
                }

                if (!posReceived || !presetAReceived || !presetBReceived) {
                    retryCount++;
                    if (oledOK) {
                        display.clearDisplay();
                        display.setCursor(0, 0);
                        display.println("Retry Data...");
                        display.setCursor(0, 10);
                        display.println(Ethernet.localIP());
                        display.display();
                    }
                    delay(1000);
                }
            }
        }

        if (oledOK) {
            display.clearDisplay();
            display.setCursor(0, 0);
            if (posReceived && presetAReceived && presetBReceived) {
                display.println("Data Loaded");
            } else {
                display.println("Data Failed");
            }
            display.setCursor(0, 10);
            display.println(Ethernet.localIP());
            display.display();
        }
    } else {
        Serial.println(F("Mode: NRF24"));
        if (oledOK) {
            display.setCursor(0, 0);
            display.println("NRF24 Mode");
            display.display();
        }
    }

    Serial.println(F("9. NRF24 init..."));
    if (radio.begin()) {
        Serial.println(F("NRF24: Initialized OK"));
        radio.setPALevel(RF24_PA_LOW);
        radio.setDataRate(RF24_250KBPS);
        radio.setChannel(76);
        radio.setAutoAck(false);
        radio.openReadingPipe(0, rfAddress);
        radio.startListening();
    } else {
        Serial.println(F("NRF24: INIT FAILED"));
    }

    setupComplete = posReceived && presetAReceived && presetBReceived;
    Serial.print(F("setupComplete = ")); Serial.println(setupComplete ? F("true") : F("false"));
    Serial.println(F("=== Boot complete, entering loop ==="));
}

void loop() {
    if (ethernetActive) {
        handleUDPRequests();
    } else {
        handleNRF24Requests();
    }
    unsigned long currentMillis = millis();
    if (currentMillis - previousMillis >= updateInterval) {
        controlStepperMotors();
        previousMillis = currentMillis;
    }
    stepper1.runSpeed();
    stepper2.runSpeed();
    stepper3.runSpeed();
    stepper4.runSpeed();

    if (currentMillis - previousDisplayMillis >= displayInterval) {
        previousDisplayMillis = currentMillis;
        updateOLEDPositions();
    }
}

// ============================================================
// NRF24 HANDLER
// ============================================================
void handleNRF24Requests() {
    if (!radio.available()) return;

    radio.read(&rxPacket, sizeof(rxPacket));

    // Verify magic byte
    if (rxPacket.magic != 0xAB) return;

    // Verify XOR checksum
    uint8_t calcChecksum = 0;
    uint8_t* p = (uint8_t*)&rxPacket;
    for (uint8_t i = 0; i < sizeof(ControllerPacket) - 1; i++) {
        calcChecksum ^= p[i];
    }
    if (calcChecksum != rxPacket.checksum) return;

    // --- Joystick: map -100..100 to -1.0..1.0 ---
    x_axis_value_left  = rxPacket.lx / 100.0;
    y_axis_value       = rxPacket.ry / 100.0;
    x_axis_value_right = rxPacket.rx / 100.0;
    float ly = rxPacket.ly / 100.0;
    trigger_right = (ly > 0) ? ly : 0;
    trigger_left  = (ly < 0) ? -ly : 0;

    // --- Button edge detection (rising edge only) ---
    uint8_t rising = rxPacket.buttons & ~lastRemoteButtonMask;
    lastRemoteButtonMask = rxPacket.buttons;

    if (rising & 0x02) savePresetA();
    if (rising & 0x40) savePresetB();
    if (rising & 0x08) recallPresetA();
    if (rising & 0x10) recallPresetB();
    if (rising & 0x04 && !autoLoopRunning) startAutoLoop();

    // Debug print every packet
    Serial.print(F("NRF24 RX  LX:")); Serial.print(rxPacket.lx);
    Serial.print(F(" LY:")); Serial.print(rxPacket.ly);
    Serial.print(F(" RX:")); Serial.print(rxPacket.rx);
    Serial.print(F(" RY:")); Serial.print(rxPacket.ry);
    Serial.print(F(" BTN:")); Serial.print(rxPacket.buttons, HEX);
    if (rising) { Serial.print(F(" RISING:")); Serial.print(rising, HEX); }
    Serial.println();
}

// ============================================================
// OLED DISPLAY
// ============================================================
void updateOLEDPositions() {
    if (!oledOK) return;
    display.clearDisplay();
    display.setTextSize(1);
    display.setTextColor(SSD1306_WHITE);
    display.setCursor(0, 0);
    display.print(F("SLD:")); display.println(stepper1.currentPosition());
    display.print(F("PAN:")); display.println(stepper2.currentPosition());
    display.print(F("TLT:")); display.println(stepper3.currentPosition());
    display.display();
}

// ============================================================
// AUTO LOOP (blocking, queries Uno after each preset)
// ============================================================
void startAutoLoop() {
    autoLoopRunning = true;
    Serial.println(F("Auto-loop started"));
    while (true) {
        recallPresetA();
        if (!queryUnoLoopState()) break;
        recallPresetB();
        if (!queryUnoLoopState()) break;
    }
    Serial.println(F("Auto-loop stopped"));
    autoLoopRunning = false;
}

// Send query to Uno and wait for response. Returns true if Uno says loop enabled.
bool queryUnoLoopState() {
    Serial.println(F("Querying loop state..."));

    ControllerPacket query;
    query.magic = 0xBA;
    query.lx = 0; query.ly = 0; query.rx = 0; query.ry = 0;
    query.buttons = 0;
    query.checksum = query.magic;

    radio.stopListening();
    delay(2);
    radio.write(&query, sizeof(query));

    radio.startListening();
    delay(2);

    unsigned long start = millis();
    while (millis() - start < 100) {
        if (radio.available()) {
            ControllerPacket resp;
            radio.read(&resp, sizeof(resp));
            if (resp.magic == 0xAB) {
                uint8_t calc = resp.magic ^ resp.lx ^ resp.ly ^ resp.rx ^ resp.ry ^ resp.buttons;
                if (calc == resp.checksum) {
                    bool state = (resp.buttons & 0x80) != 0;
                    Serial.print(F("Loop state: ")); Serial.println(state ? F("true") : F("false"));
                    return state;
                }
            }
        }
    }
    Serial.println(F("Query timeout -> false"));
    return false;
}

void handleUDPRequests() {
    int packetSize = Udp.parsePacket();
    if (packetSize) {
        int len = Udp.read(packetBuffer, 255);
        if (len > 0) packetBuffer[len] = 0;
        String request = String(packetBuffer);

        if (request.startsWith("SET_JOYSTICK")) {
            int firstComma = request.indexOf(',');
            int secondComma = request.indexOf(',', firstComma + 1);
            int thirdComma = request.indexOf(',', secondComma + 1);
            int fourthComma = request.indexOf(',', thirdComma + 1);

            String x_axis_left_str = request.substring(13, firstComma);
            String x_axis_right_str = request.substring(firstComma + 1, secondComma);
            String y_axis_str = request.substring(secondComma + 1, thirdComma);
            String trigger_left_str = request.substring(thirdComma + 1, fourthComma);
            String trigger_right_str = request.substring(fourthComma + 1);

            x_axis_value_left = x_axis_left_str.toFloat();
            x_axis_value_right = x_axis_right_str.toFloat();
            y_axis_value = y_axis_str.toFloat();
            trigger_left = trigger_left_str.toFloat();
            trigger_right = trigger_right_str.toFloat();
        } else if (request.startsWith("SEND_CURRENT_POS")) {
            if (setupComplete) {
                sendCurrentMotorPositions();
            }
        } else if (request.startsWith("SAVE_POS")) {
            saveMotorPositions();
        } else if (request.startsWith("RECALL_POS")) {
            recallMotorPositions();
        } else if (request.startsWith("SAVE_A")) {
            savePresetA();
        } else if (request.startsWith("SAVE_B")) {
            savePresetB();
        } else if (request.startsWith("RECALL_A")) {
            recallPresetA();
        } else if (request.startsWith("RECALL_B")) {
            recallPresetB();
        } else if (request.startsWith("UPDATE_LOOP")) {
            loopPresets = request.substring(12) == "true";
        } else if (request.startsWith("INCREASE_SPEED")) {
            msSpeed += 200;
            max_speed_left = msSpeed;
            sendMsSpeed();
        } else if (request.startsWith("DECREASE_SPEED")) {
            msSpeed -= 200;
            max_speed_left = msSpeed;
            sendMsSpeed();
        }
    }
}

void controlStepperMotors() {
    int target_speed_left = applyDeadzoneAndRemap(x_axis_value_left * 100, -100, 100, -max_speed_left, max_speed_left);
    int target_speed_right = applyDeadzoneAndRemap(x_axis_value_right * 100, -100, 100, -max_speed_right, max_speed_right);
    int target_speed_y = applyDeadzoneAndRemap(y_axis_value * 100, -100, 100, -max_speed_y, max_speed_y);
    int target_speed_zoom = applyDeadzoneAndRemap((trigger_right + trigger_left) * 100, -100, 100, -max_speed_zoom, max_speed_zoom);

    float speed_diff_left = target_speed_left - current_speed_left;
    if (speed_diff_left > 0) {
        current_speed_left += min(acceleration_rate_left, speed_diff_left * 0.002 + 0.02);
        if (current_speed_left > target_speed_left) current_speed_left = target_speed_left;
    } else if (speed_diff_left < 0) {
        current_speed_left -= min(deceleration_rate_left, -speed_diff_left * 0.002 + 0.02);
        if (current_speed_left < target_speed_left) current_speed_left = target_speed_left;
    }

    if (target_speed_right > current_speed_right) {
        current_speed_right += acceleration_rate_right;
        if (current_speed_right > target_speed_right) current_speed_right = target_speed_right;
    } else if (target_speed_right < current_speed_right) {
        current_speed_right -= deceleration_rate_right;
        if (current_speed_right < target_speed_right) current_speed_right = target_speed_right;
    }

    if (target_speed_y > current_speed_y) {
        current_speed_y += acceleration_rate_y;
        if (current_speed_y > target_speed_y) current_speed_y = target_speed_y;
    } else if (target_speed_y < current_speed_y) {
        current_speed_y -= deceleration_rate_y;
        if (current_speed_y < target_speed_y) current_speed_y = target_speed_y;
    }

    if (target_speed_zoom > current_speed_zoom) {
        current_speed_zoom += acceleration_rate_zoom;
        if (current_speed_zoom > target_speed_zoom) current_speed_zoom = target_speed_zoom;
    } else if (target_speed_zoom < current_speed_zoom) {
        current_speed_zoom -= deceleration_rate_zoom;
        if (current_speed_zoom < target_speed_zoom) current_speed_zoom = target_speed_zoom;
    }

    stepper1.setSpeed(current_speed_left);
    stepper2.setSpeed(current_speed_right);
    stepper3.setSpeed(current_speed_y);
    stepper4.setSpeed(current_speed_zoom);
}

int applyDeadzoneAndRemap(float input, int minInput, int maxInput, int minOutput, int maxOutput) {
    if (abs(input) < deadzone) return 0;
    int adjustedInput = (input > 0) ? input - deadzone : input + deadzone;
    int adjustedMaxInput = maxInput - deadzone;
    return map(adjustedInput, -adjustedMaxInput, adjustedMaxInput, minOutput, maxOutput);
}

void sendCurrentMotorPositions() {
    String message = "CURRENT_POS:";
    message += String(stepper1.currentPosition()) + ",";
    message += String(stepper2.currentPosition()) + ",";
    message += String(stepper3.currentPosition()) + ",";
    message += String(stepper4.currentPosition());
    sendUDPMessage(message.c_str());
}

void sendMsSpeed() {
    String message = "MSSPEED:" + String(msSpeed);
    sendUDPMessage(message.c_str());
}
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

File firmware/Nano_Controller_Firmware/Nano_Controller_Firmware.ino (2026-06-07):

// ============================================================
// Nano/Uno Controller - Transmitter Firmware
// Sends joystick + button data to Mega via NRF24
// Menu mode for settings (Start toggles), saved to EEPROM
// ============================================================

#include <SPI.h>
#include <RF24.h>
#include <Wire.h>
#include <Adafruit_GFX.h>
#include <Adafruit_SSD1306.h>
#include <EEPROM.h>

// --- NRF24 pins ---
#define CE_PIN  8
#define CSN_PIN 9
RF24 radio(CE_PIN, CSN_PIN);
const byte rfAddress[6] = "00001";

// --- OLED ---
#define SCREEN_WIDTH  128
#define SCREEN_HEIGHT 64
#define OLED_RESET    -1
Adafruit_SSD1306 display(SCREEN_WIDTH, SCREEN_HEIGHT, &Wire, OLED_RESET);
bool oledOK = false;

// --- Joystick pins ---
#define L_JOY_X  A0
#define L_JOY_Y  A1
#define R_JOY_X  A2
#define R_JOY_Y  A3

// --- Button pins ---
#define BTN_START   2
#define BTN_X       3
#define BTN_Y       4
#define BTN_DPAD_L  5
#define BTN_DPAD_R  6
#define BTN_A       7
#define BTN_B       10

const uint8_t buttonPins[] = { BTN_START, BTN_X, BTN_Y, BTN_DPAD_L, BTN_DPAD_R, BTN_A, BTN_B };
const char* buttonLabels[] = { "START", "X", "Y", "D-L", "D-R", "A", "B" };
const uint8_t NUM_BUTTONS = 7;

// Button bitmasks
#define MASK_START  0x01
#define MASK_X      0x02
#define MASK_Y      0x04
#define MASK_DPAD_L 0x08
#define MASK_DPAD_R 0x10
#define MASK_A      0x20
#define MASK_B      0x40

// --- Compact binary packet ---
struct __attribute__((packed)) ControllerPacket {
    uint8_t magic;
    int8_t  lx;
    int8_t  ly;
    int8_t  rx;
    int8_t  ry;
    uint8_t buttons;
    uint8_t checksum;
};
ControllerPacket txPacket;

// --- Modes ---
enum Mode { MODE_NORMAL, MODE_MENU };
Mode currentMode = MODE_NORMAL;

// --- Settings (persisted in EEPROM) ---
struct Settings {
    uint8_t magic;
    uint8_t sensitivity;   // 0-100 (default 70)
    uint8_t invertMask;    // bit0=LX, bit1=LY, bit2=RX, bit3=RY
    uint8_t speedScale;    // 0-100 (default 100)
};
Settings settings;
#define EEPROM_ADDR 0
#define SETTINGS_MAGIC 0x42

// --- Menu ---
const char* menuItems[] = {
    "Sensitivity",
    "Invert LX",
    "Invert LY",
    "Invert RX",
    "Invert RY",
    "Speed Scale"
};
const uint8_t MENU_COUNT = 6;
uint8_t menuIndex = 0;

// --- Button state ---
uint8_t lastButtonMask = 0;
bool loopEnabled = false; // Y sets true, X sets false; queried by Mega after each preset

// --- Joystick calibration ---
int joyCenter[4];

// --- Timing ---
unsigned long lastTxTime = 0;
const unsigned long TX_INTERVAL = 50; // 20 Hz

// --- TX diagnostics ---
uint16_t txOkCount = 0;
uint16_t txFailCount = 0;

// ============================================================
void setup() {
    Serial.begin(115200);

    // Init buttons
    for (uint8_t i = 0; i < NUM_BUTTONS; i++) {
        pinMode(buttonPins[i], INPUT_PULLUP);
    }

    // Init OLED
    Wire.begin();
    delay(100);
    oledOK = display.begin(SSD1306_SWITCHCAPVCC, 0x3C);
    if (oledOK) {
        display.clearDisplay();
        display.setTextSize(1);
        display.setTextColor(SSD1306_WHITE);
        display.setCursor(0, 0);
        display.println(F("Nano Controller"));
        display.display();
    } else {
        Serial.println(F("OLED not found"));
    }

    // Load settings from EEPROM
    loadSettings();

    // Calibrate joystick centers
    delay(200);
    joyCenter[0] = analogRead(L_JOY_X);
    joyCenter[1] = analogRead(L_JOY_Y);
    joyCenter[2] = analogRead(R_JOY_X);
    joyCenter[3] = analogRead(R_JOY_Y);

    // Init NRF24
    if (!radio.begin()) {
        Serial.println(F("NRF24 not found!"));
        if (oledOK) {
            display.println(F("NRF24 ERROR"));
            display.display();
        }
        while (1) {} // Halt
    }
    radio.setPALevel(RF24_PA_LOW);
    radio.setDataRate(RF24_250KBPS);
    radio.setChannel(76);
    radio.setAutoAck(false);
    radio.openWritingPipe(rfAddress);
    radio.stopListening();

    Serial.println(F("NRF24 TX ready"));
    if (oledOK) {
        display.println(F("NRF24 OK"));
        display.display();
        delay(1000);
    }
}

// ============================================================
void loop() {
    uint8_t currentMask = readButtonMask();

    // --- START button: toggle Normal / Menu ---
    bool startPressed = (currentMask & MASK_START) && !(lastButtonMask & MASK_START);
    if (startPressed) {
        if (currentMode == MODE_NORMAL) {
            enterMenu();
        } else {
            exitMenu();
        }
    }

    if (currentMode == MODE_NORMAL) {
        doNormalMode(currentMask);
    } else {
        doMenuMode(currentMask);
    }

    lastButtonMask = currentMask;
    delay(20); // ~50 Hz input poll
}
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

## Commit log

2026-06-04 Initial commit: Slider Design V2
    [2040_slider_carriage_bottomV1.stl, 2040_slider_carriage_topV1.stl, CameraUplateV1.stl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]
2026-06-07 Add code map document and update project status with archive details
    [3mm_to_5mm_wheel_bearing_spacer_centred.stl, PanBearingHolderV1.stl]
